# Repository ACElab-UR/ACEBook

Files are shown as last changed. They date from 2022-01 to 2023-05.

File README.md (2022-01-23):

# Animal Comparative Economics Book

This repository contains the source code for the **ACEBook** - ACElab's online JupyterBook.

All code in this project was written in and tested with R 3.xx and Python 3.xx, though older language versions (including R 2.xx and Python 2.7) should work in most cases.

## Usage

### Building the book

If you'd like to develop and/or build the ACEBook, you should:

- Clone this repository
- `cd` to it and run `pip install -r requirements.txt` (it is recommended you do this within a virtual environment - i.e. conda)
- (Recommended) Remove the existing `ACEBook/content/_build/` directory
- Run `jupyter-book build ...` (more on this below)

A fully-rendered HTML version of the book will be built in `ACEBook/_build/html/`.

### Hosting/Deploying the book online

The html version of the book is hosted on the `gh-pages` branch of this repo, which is then rendered on [https://acelab-ur.github.io/ACEBook/](https://acelab-ur.github.io/ACEBook/). 

The following workflow is used to build the book manually:

- Make changes to the book's content on the master branch of this repository
- Re-build the book with `jupyter-book build content` (assumes you are running the command from *root* directory of the repository)
- Ensure that an HTML has been built for each page of your book. There should be a collection of HTML files in the `content/_build/html` folder. Also load `_build/html/notebooks/index.html` and check that the book has been built (with navigation etc.) as expected. 
- Run `ghp-import -n -p -f content/_build/html` to deploy the book.
 
The last command will automatically push the latest build to the `gh-pages` branch. More information on this hosting process can be found [here](https://jupyterbook.org/publish/gh-pages.html#manually-host-your-book-with-github-pages).

Typically after a few minutes the site should be viewable online at [https://acelab-ur.github.io/ACEBook/](https://acelab-ur.github.io/ACEBook/). If not, check repository settings under Options -> GitHub Pages to ensure that the gh-pages branch is configured as the build source for GitHub Pages.

An example command to push all new changes to the git repository is:

`git add -A && git commit -m "Commit message" && git push -u origin master`

**Please do not push changes for every little edit you make to the book (e.g., after fixing some typos)**. Push only significant changes. Remember, you can deploy the book (by pushing to the `gh-pages` branch using `ghp-import` as explained above) without pushing changes to the `master` branch.

## Other tips:

* Read the [Jupyter Book](https://jupyterbook.org/intro.html) - This is short and to the point and addresses all of the key tools and guidelines succinctly 

* If you want to remove a particular cell from the rendered book [see this](https://jupyterbook.org/interactive/hiding.html#removing-code-cell-content)
  
* If you want to remove a cell when exporting a Jupyter Notebook (outside of Jupyter Book), say as an html, add 
 ```json
    {
    "tags": [
        "remove_cell"
        ]
    }
```
to the metadata of the cells that you want to remove from the output, and then run: 
  ```bash
  jupyter nbconvert younotebookname.ipynb --TagRemovePreprocessor.enabled=True --TagRemovePreprocessor.remove_cell_tags="['remove_cell']" --to html
  ```
  (`html` can be replaced with another export format, such as `pdf`). Read the [`nbconvert` documentation](https://nbconvert.readthedocs.io/en/latest/index.html) for more on exporting/converting.

## Contributors

Henrique Galante | henrique.galante@ur.de

## Credits

This project is created using the excellent open source [Jupyter Book project](https://jupyterbook.org/) and the [executablebooks/cookiecutter-jupyter-book template](https://github.com/executablebooks/cookiecutter-jupyter-book).

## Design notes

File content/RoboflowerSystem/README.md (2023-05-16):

# Roboflower System

Welcome to the repository of the Roboflower system!

The Roboflowers are automated artificial flowers from the [ACElab](https://www.animal-economics.com/tjczaczkes) used in behavioural experiments on bumblebees. This READme file details everything about the system, from building the roboflowers to programming experiments, as well as debugging the system. 

Please refer to this document before using the Roboflowers.

## Files in the repository:

### Instructions
Find the readme files to assemble, program and debug the Roboflowers:

- Programming.md
- Assemblingflowers.md
- Harware.md

### Versions
Find the annotated python modules for each Roboflowers' version

### Circuit
Find the schematics and gerber files for the Roboflowers' PCB

### Misc
Find the aruco codes and various files for updating the Roboflower system

## Log changes:
Track the changes brought to the Roboflowers in each version:

### V2023.03.12:
- all python modules are now annotated for clarity
- pumps now have individual calibration rather than one calibration for all 4 pumps per flower
- new operating system for the roboflowers:
	- latest upgrades and updates for packages
- main.py of the HUB re-written in a simpler way
- connect.py (HUB) modifications:
	- the connection with the flowers is now checked every minute 
- main.py (Flower) modifications:
	- pumps' UlForTurn are now invididually precised for each roboflower
	- routine for testing that the RGB LEDs are working properly
- connect.py of the Flower modifications:
	- addition of a "on_disconnect" function that tries to reconnect the flower if it loses the connection with the broker
- electronics.py of the Flower modifications:
	- addition of the parameter "UlForTurn" in the Pump class
	- addition of the parameter "duration" in the blink method
	- precision of the exact volumes delivered in the priming routine in the "prime" function

### V2023.04.13:
In this version: the roboflowers are stable and work well!
- corrected the "too many values to unpack" bugs in routines.py
- fixed the on_disconnect function in both connect.py
- all modules further annotated for clarity
- improved the way log and debug files are written
- corrected the camera error in colonylearn

### V2023.05.04:
- in Electronics:
 	- increased the amount flushed out by the empty pump from 20 to 25ul (to avoid any leaking risk due to calibration imprecision)
 	- in the clean() function, empty pump now flushes out 25ul instead of 21ul 
 	- changed back the "error" from -100/100 to -95/95 for the pumps
- hardware:
 	- changed the big milkers for glass bottles which are no longer suspended above the flowers (reduce capillary action in the tubes + risk of flooding the flowers)
 	- removed the glass pieces in the flowers because of condensation and droplets

### V2023.05.16:
- fixed marker detection

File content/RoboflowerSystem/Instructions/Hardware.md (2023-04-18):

# Hardware
In this section are detailed the specifics of the different electronic components of the Roboflowers.

## Motors
The Roboflowers use [mini brushed DC stepper motors](https://ecksteinimg.de/Datasheet/MO01052/Datenblatt.pdf) (see specifications of the motor)

**What is a stepper motor?**

Stepper motors are DC motors that move in discrete steps. They have multiple coils that are organized in groups called "phases". By energizing each phase in sequence, the motor will rotate, one step at a time. Typical stepper motors are 1.8 degrees per step, which is 200 steps per revolution.

**How to control the motors?**

On the PCB, the two [H-bridges](https://www.ti.com/lit/ds/symlink/l293d.pdf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) (= integrated circuits that enable a voltage to be applied in either direction) are responsible for controlling the motors of the pumps. 
These H-bridge include four independent half-H drivers that can control the direction and speed of DC motors. In our setup, the H-brigdes also serve as our stepper motors' driver boards. 

By sending signals through its GPIO pins, the Raspberry Pi can control the flow of current through the H-bridge circuits, hence controlling the movement of each peristaltic pump.
The Roboflowers have 2 full H-bridges:
- one is used to control the forward movement of the motors, providing a positive voltage
- the other is used to control the backward movement of the motors, providing a negative voltage

To move the motor in one direction, one pair of coils needs to receive a current while the other pair needs to be turned off.

## Pumps
In order to deliver precise amounts of liquid, our motors are programmed precisely to prevent issues such as missed steps or motor vibration. Some basics:
- delay: is the time interval between each step that the motor takes. This is an important parameter that determines the speed of the motor. The smaller the delay, the faster the motor will spin.
- static: is used to determine if the motor is stuck or not. In the code, static is a counter that keeps track of how many times the error is within a certain threshold (in this case, between -5 and 5): if the error is within the threshold for a certain number of times, it means the motor is not stuck and can continue to move.
- updatedspeed: this variable is the new speed that the motor will move at, based on the error calculated from the desired volume and the current position of the motor. It is calculated as error * 0.045 
- 0.045: is the constant that determines the relationship between the error and the updated speed. Increasing this value makes the motor turn faster because the updatedspeed variable is directly proportional to the error: increasing the constant can help to prevent the motor from getting stuck by ensuring that it is running at a fast enough speed to overcome any resistance or friction.
- 100 and -100: These are the minimum and maximum values for the updated speed

In the class Pump of the module electronics, each pump has its "UlForTurn" own method [*modification brought in the V2023.03.12*]
The "stepsForTurn" method corresponds to the number of steps required for the pump to make a full turn. This value is fixed and determined
by the design of the motor. In our design, 700steps make one full pump turn.

## PCB and components
The Printed Circuit Board is the "blue board" designed especially for the Roboflowers. It is used to connect and control the electronic components of the Roboflower, such as the LEDs and the motors.

Elements on the [PCB](file:///C:/Users/saaa/Documents/bumblebee_documents/RoboFlowerSystem/Circuit/Schematic_PeakEndFlowerShield%20H-bridge_2022-02-22.pdf) (Refer to the schematics for more info):
- U1 in the schematics represents the Raspberry pi <=> the 40 GPIO pins precisely
- JP1 - JP4: connectors for the pumps
- U2 and U3: H-bridges for controlling the motors of the pumps
- J2 + R13-14-15: connector for the two RGB LEDs: the one under the platform and the one in front of the roboflower
- U8: MT3608 Step Up <=> voltage booster or voltage regulator module that can increase the voltage level of the input voltage to a higher level

**J2 8p 2mm connector:**

"J" stands for "jack", convention used in electronics to name connectors. This connector is for the 2 RGB LEDs of the Roboflowers, which have 7 pins (2black wires connected to the same pin) spaced 2mm apart.

The J2 connector is connected to the two RGB LEDs using eight wires for 7 pins: two black wires for the anode and cathode (= connected to ground for all LEDs), two blue wires, two green wires, and two red wires. RGB LEDs are light emitting diodes that can produce a range of colors by varying the intensity of red, green, and blue light. The two RGB LEDs are wired in parallel and connected to the J2 connector.
The two RGB LEDs  receive the same voltage and current and emit the same colors at the same time, being wired in parallel. The Raspberry Pi sends the same PWM (Pulse Width Modulation) signals to each of the red, green, and blue elements of the LED to control the brightness and color of the LED.
Typically, the red wire is the positive (+) voltage supply, the black wire is the negative (-) voltage supply or ground, and the other wires are for the individual color channels of the RGB LED.

For example, one green wire might be connected to the green channel of the first RGB LED, and the other green wire might be connected to the green channel of the second RGB LED. The same applies to the other color channels, so there should be one red wire and one black wire for each RGB LED, and two wires for each of the three color channels (red, green, and blue).

**U1 (= Raspberry Pi):**

"U" is often used to represent an integrated circuit or, chip. These are small electronic components that contain many electronic circuits on a single chip of semiconductor material. They are often used in complex electronic systems to perform various functions. U1 means the first chip or integrated circuit in the circuit. U1 is the Raspberry Pi, responsible for controlling and communicating with all the other components on the PCB through its 40 GPIO pins.

**JP1 - JP4: connectors for the pumps:**

"JP" (for jumper) is a small piece of hardware that is used to connect two points or terminals on a circuit board. It is usually a small plastic block with pins. JP1 to JP4 are connectors for the motors of the roboflowers. They allow the motors to be easily connected and disconnected from the rest of the circuit.

Each JP connector has 6pins connected to 6 wires of the following colours: white, blue, green, yellow, black and red.
- white: is the "step" pin, which controls the movement of the stepper motor. The stepper motor moves in precise steps, and each step is triggered by a pulse on this pin
- blue: is the "direction" pin, which controls the direction of the stepper motor. Depending on the signal on this pin, the motor will move in either a clockwise or counterclockwise direction
- green: is the "enable" pin, which allows the motor to be turned on and off. When this pin is high, the motor is enabled and can move. When it's low, the motor is disabled and won't move
- yellow: is the "MS1" pin, which controls the microstepping mode of the motor driver. Microstepping allows for smoother and more precise movements of the motor, but it also requires more processing power and can be slower than full-step mode
- black: is the "ground" pin, which provides a reference voltage for the other pins.
- red: is the "power" pin, which provides the voltage for the motor

**U2 and U3: H-Bridges for the motors:**

the H-bridges are connected to the JP1 to JP4 connectors and to the GPIO pins on the Raspberry Pi. Some of the GPIO pins of the Raspberry pi are specifically connected to the H-bridges to control the direction and speed of the motors.

**U8, MT3608 Step Up:**

The MT3608 Step Up is a DC-DC converter that is commonly used to step up the voltage from a lower voltage source to a higher voltage level. The Raspberry Pi's GPIO pins provide a 5V voltage level, but our motors require a 6V voltage level. The MT3608 Step Up module has an inductor and a switching transistor. There is a back and forth exchange of current between the two change the magnetic which causes to change the voltage. Once the voltage has been boosted to 6V, it is sent to the motors through the H-bridge drivers, allowing the motors to operate at their optimal voltage level.

# Fixing hardware
In this section are detailed the most common problems you may face with the hardware.

## Pump problems

### One pump turns non-stop:
- Wiring issue: the signal to turn off the pump is not being received: double-check the wiring connections (green LED of the motor should be on)
- Calibration issue: the flow rate for the faulty pump is not properly set. Check the calibration values for this pump
- Motor issue: the pump is not responding to the signal to turn off. Try replacing the motor with a new one and see if the issue persists
- Mechanical issue: check the pump for any blockages or obstructions that may be preventing it from functioning properly

### One pump is turning in the wrong direction:
- Direction issue: check that the pump is turning anticlockwise when delivering solution from the bottle to the feeder
- Pump was mounted wrong: check that the pump was assembled correctly (see: AssemblingFlowers.md)
- Connector issue: check that the wires on the JP connectors are mounted correctly: white, blue, green, yellow, black and red

### The motor is vibrating but does not turn:
When a motor vibrates, it means it’s not receiving enough power to move past its initial position, so the motor is just moving very slowly. Check that the current received by the motor is enough (6V):
- set the multimeter to measure DC voltage: place cursor on 20V
- connect the probes to the power supply terminals of the motor:
	- the positive probe (red) touching the red wire on the JP connector
	- the negative probe (black) touching the black wire on the connector
	- make sure the motor is running while you take the measurement: this will give you an accurate reading of the voltage being supplied to the motor while it is under load
- lubricate the motor that gets stuck
- change constant in the code (0.045) and/or add time.sleep between each step motor step

## LEDs problems

### One of the LED doesn't light up during the routine when starting a Roboflower:
- Faulty LED: try swapping the LED with a known-working LED to see if the problem is with the LED itself
- Wiring issue: check the connections on the PCB and the J2 connector to ensure that the wires are connected properly and not loose
- Power issue: the power supply to the LED is not sufficient and is not getting enough voltage to light up. check the voltage levels using a multimeter to ensure that the power supply is providing the correct voltage:
    - Red LEDs typically require a voltage of around 1.8 to 2.2 volts to light up
    - Blue LEDs: around 3.0 to 3.6 volts to light up
    - Green LEDs: around 2.0 to 3.6 volts to light up

How to check the voltage levels of the LEDs with a multimeter:
- set the multimeter to measure DC voltage (usually denoted as V with a straight line and a dashed line above it)
- connect the black probe of the multimeter to the ground (GND) pin <=> touch the black pin of the connector on the PCB
- connect the red probe of the multimeter to the positive (+) pin of the power supply <=> touch the coloured pin of the connector on the PCB

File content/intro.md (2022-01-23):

Welcome to The Animal Comparative Economics Book!
===================================================

```{epigraph}
Animals must constantly make economic decisions to survive. Understanding the preference for one option over another is key to decision making. We are building on insights from the study of behavioural economics and cognitive psychology in order to understand how animals evaluate options, and thus make decisions, both alone and collectively.
Our research focuses mostly on invertebrates, especially ants, as they offer a fast and flexible platform for testing decision making.
```

## Team
<hr style="border:2px solid gray"> </hr>

### PD Dr. Tomer J. Czaczkes
**Team Leader**  
Leads all ACE research projects, and is also involved in a wide variety of behavioural ecology projects. Collects data on occasion.
 
### Dr. Massimo de Agro
**Post-Doctoral Researcher**  
In charge of developing a robotic flower meadow for our bumblebees. Cameras! Micro-computers! Lots and lots of mini-pumps! Also does spider vision research in his spare time.

### Mélissa Armand
**Doctoral Researcher**  
Studies how plants may be using behavioural economics to manipulate pollinators - in our case bumblebees.

### Henrique Galante
**Doctoral Researcher**  
Studies how preference can be steered in Argentine ants using behavioural economics and comparative psychology. Works closely with Thomas Wagner.

### Thomas Wagner
**Doctoral Researcher**  
Studies how preference can be steered in Argentine ants using behavioural economics and comparative psychology. Works closely with Henrique Galante.

### Alexandra Koch
**Research Assistant**  
A long-term fixture in the ACElab, Alex does... everything.

### MSc & BSc students
Sophie Schmid - **BSc thesis**  
The effect of urban heat islands on ant behaviour

Melina Kienitz - **BSc thesis**  
Visual discrimination of sucrose in Bumblebees

### PhD Alumni
Dr. Felix Oberhauser  
Dr. Stephanie Wendt  
Dr. Massimo de Agro

### MSc and BSc Alumni
Chiara Matschunas  
Melanie Kabas  
Alexandra Koch  
St. Popp  
Caroline Hübner  
Jack Beckwith  
Daniel Grimwade  
Pragya Kumar  
Stealth Human  
Countless 3-week and 6-week practical students: you know who you are!

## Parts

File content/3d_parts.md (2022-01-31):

# 3D Printing
## Feeders

<font size = "+0"> <b> <a href = "https://github.com/ACElab-UR/ACEBook/raw/main/content/3D_Parts/water_feeder.stl" download = "water_feeder.stl" style = "color: DarkOrange" > Water Feeder </a> </b> </font>

<font size = "+0"> <b> <a href = "https://github.com/ACElab-UR/ACEBook/raw/main/content/3D_Parts/sucrose_feeder.stl" download = "sucrose_feeder.stl" style = "color: DarkOrange" > Sucrose Feeder </a> </b> </font>

<font size = "+0"> <b> <a href = "https://github.com/ACElab-UR/ACEBook/raw/main/content/3D_Parts/tiny_feeder.stl" download = "tiny_feeder.stl" style = "color: DarkOrange" > Tiny Feeder </a> </b> </font>

## Nests

<font size = "+0"> <b> <a href = "https://github.com/ACElab-UR/ACEBook/raw/main/content/3D_Parts/nest_tube_holder.stl" download = "nest_tube_holder.stl" style = "color: DarkOrange" > 15mL Falcon Holder </a> </b> </font>

## Y-Maze Parts

<font size = "+0"> <b> <a href = "https://github.com/ACElab-UR/ACEBook/raw/main/content/3D_Parts/y_maze_wall.stl" download = "y_maze_wall.stl" style = "color: DarkOrange" > Y-Maze Wall </a> </b> </font>

<font size = "+0"> <b> <a href = "https://github.com/ACElab-UR/ACEBook/raw/main/content/3D_Parts/linear_wall.stl" download = "linear_wall.stl" style = "color: DarkOrange" > Linear Wall </a> </b> </font>

<font size = "+0"> <b> <a href = "https://github.com/ACElab-UR/ACEBook/raw/main/content/3D_Parts/double_y_maze_1.stl" download = "double_y_maze_1.stl" style = "color: DarkOrange" > Double Bifurcation Y-Maze 1 </a> </b> </font>

<font size = "+0"> <b> <a href = "https://github.com/ACElab-UR/ACEBook/raw/main/content/3D_Parts/double_y_maze_2.stl" download = "double_y_maze_2.stl" style = "color: DarkOrange" > Double Bifurcation Y-Maze 2 </a> </b> </font>

## Moats & Bridges

<font size = "+0"> <b> <a href = "https://github.com/ACElab-UR/ACEBook/raw/main/content/3D_Parts/moat_vM.stl" download = "moat_vM.stl" style = "color: DarkOrange" > Moat - Massimo Version </a> </b> </font>

<font size = "+0"> <b> <a href = "https://github.com/ACElab-UR/ACEBook/raw/main/content/3D_Parts/8cm_bridge_vM.stl" download = "8cm_bridge_vM.stl" style = "color: DarkOrange" > 8cm Bridge - Massimo Version </a> </b> </font>

<font size = "+0"> <b> <a href = "https://github.com/ACElab-UR/ACEBook/raw/main/content/3D_Parts/moat_vH.stl" download = "moat_vH.stl" style = "color: DarkOrange" > Moat - Henrique Version </a> </b> </font>

<font size = "+0"> <b> <a href = "https://github.com/ACElab-UR/ACEBook/raw/main/content/3D_Parts/6cm_bridge_vH.stl" download = "6cm_bridge_vH.stl" style = "color: DarkOrange" > 6cm Bridge - Henrique Version </a> </b> </font>

<font size = "+0"> <b> <a href = "https://github.com/ACElab-UR/ACEBook/raw/main/content/3D_Parts/7cm_bridge_vH.stl" download = "7cm_bridge_vH.stl" style = "color: DarkOrange" > 7cm Bridge - Henrique Version </a> </b> </font>

<font size = "+0"> <b> <a href = "https://github.com/ACElab-UR/ACEBook/raw/main/content/3D_Parts/8cm_bridge_lego.stl" download = "8cm_bridge_lego.stl" style = "color: DarkOrange" > 8cm Bridge - Lego Version </a> </b> </font>

## Aluminium Extrusion Supports

<font size = "+0"> <b> <a href = "https://github.com/ACElab-UR/ACEBook/raw/main/content/3D_Parts/alu_profile_camera_support_4.0.stl" download = "alu_profile_camera_support.stl" style = "color: DarkOrange" > Camera Support </a> </b> </font>

<font size = "+0"> <b> <a href = "https://github.com/ACElab-UR/ACEBook/raw/main/content/3D_Parts/alu_profile_screen_support_half_1.stl" download = "alu_profile_screen_support_half_1.stl" style = "color: DarkOrange" > Screen Support 1 </a> </b> </font>

<font size = "+0"> <b> <a href = "https://github.com/ACElab-UR/ACEBook/raw/main/content/3D_Parts/alu_profile_screen_support_half_2.stl" download = "alu_profile_screen_support_half_2.stl" style = "color: DarkOrange" > Screen Support 2 </a> </b> </font>

## Volume Estimation Parts

<font size = "+0"> <b> <a href = "https://github.com/ACElab-UR/ACEBook/raw/main/content/3D_Parts/volume_estimation_base.stl" download = "volume_estimation_base.stl" style = "color: DarkOrange" > Base </a> </b> </font>

<font size = "+0"> <b> <a href = "https://github.com/ACElab-UR/ACEBook/raw/main/content/3D_Parts/volume_estimation_platform.stl" download = "volume_estimation_platform.stl" style = "color: DarkOrange" > Platform </a> </b> </font>

## Survival Assay Parts

<font size = "+0"> <b> <a href = "https://github.com/ACElab-UR/ACEBook/raw/main/content/3D_Parts/cell_culture_lid_23cm.stl" download = "cell_culture_lid_23cm.stl" style = "color: DarkOrange" > 23cm Lid </a> </b> </font>

<font size = "+0"> <b> <a href = "https://github.com/ACElab-UR/ACEBook/raw/main/content/3D_Parts/cell_culture_lid_24cm.stl" download = "cell_culture_lid_24cm.stl" style = "color: DarkOrange" > 24cm Lid </a> </b> </font>

## Assorted Parts

<font size = "+0"> <b> <a href = "https://github.com/ACElab-UR/ACEBook/raw/main/content/3D_Parts/plate_cleaner.sl1" download = "plate_cleaner.sl1" style = "color: DarkOrange" > SL1 Plate Cleaner </a> </b> </font>

<font size = "+0"> <b> <a href = "https://github.com/ACElab-UR/ACEBook/raw/main/content/3D_Parts/vaccum_plug.stl" download = "vaccum_plug.stl" style = "color: DarkOrange" > Vaccum Plug </a> </b> </font>

<font size = "+0"> <b> <a href = "https://github.com/ACElab-UR/ACEBook/raw/main/content/3D_Parts/epi_holder.stl" download = "epi_holder.stl" style = "color: DarkOrange" > Eppendorf Holder </a> </b> </font>

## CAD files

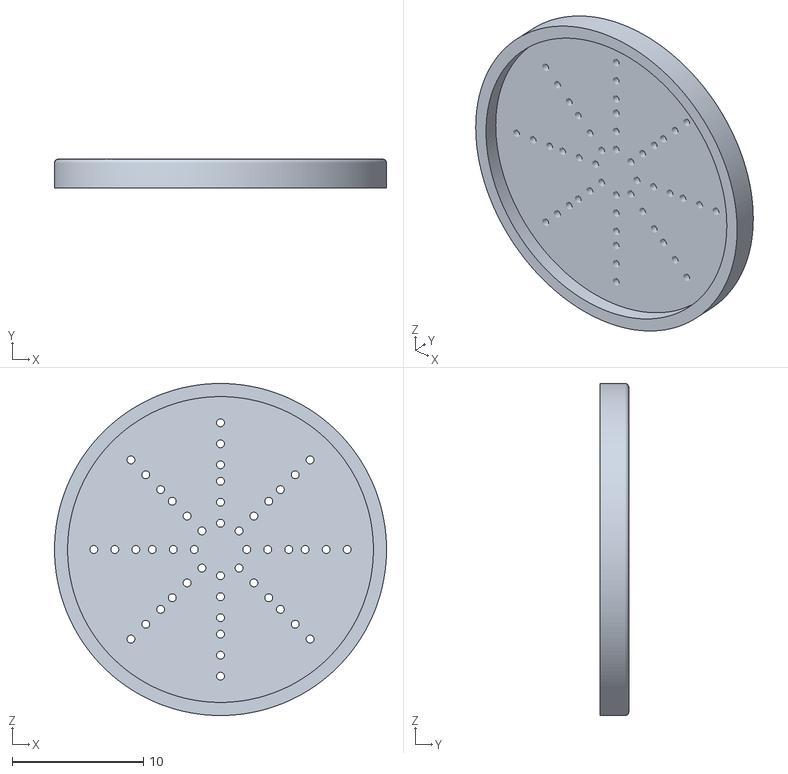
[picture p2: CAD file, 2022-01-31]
content/3D_Parts/cell_culture_lid_23cm.stl
25.3 x 2.20 x 25.3

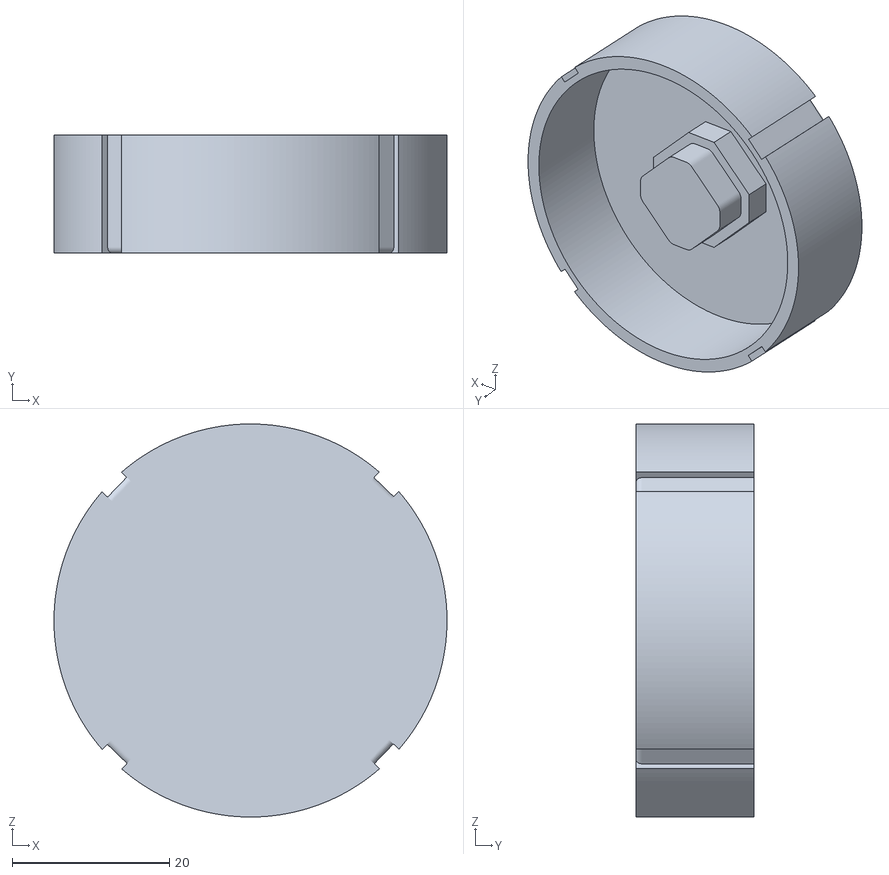
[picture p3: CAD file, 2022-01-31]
content/3D_Parts/moat_vH.stl
50.0 x 15.0 x 50.0

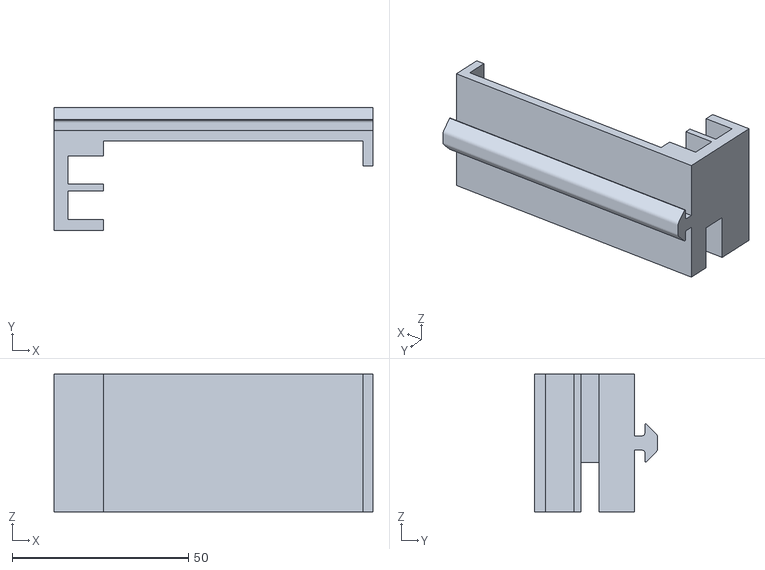
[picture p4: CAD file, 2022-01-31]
content/3D_Parts/alu_profile_screen_support_half_1.stl
90.5 x 35.0 x 39.1

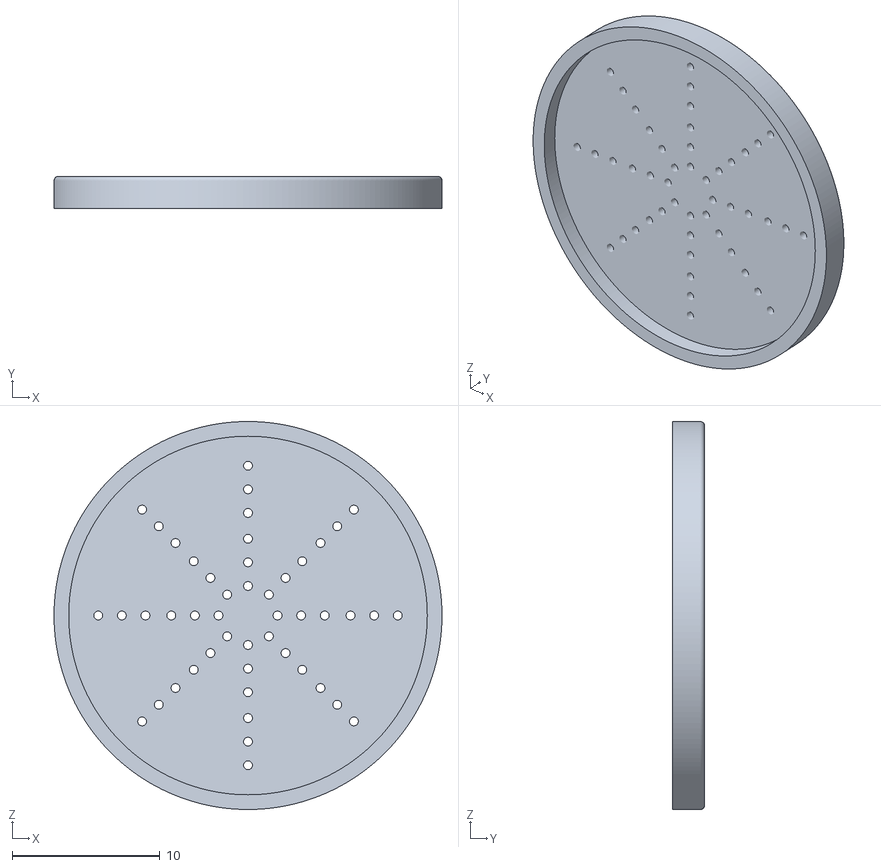
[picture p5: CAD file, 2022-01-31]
content/3D_Parts/cell_culture_lid_24cm.stl
26.3 x 2.20 x 26.3

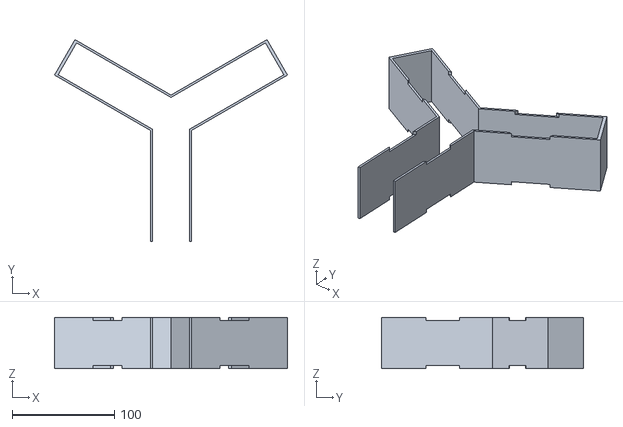
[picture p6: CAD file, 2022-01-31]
content/3D_Parts/y_maze_wall.stl
227.8 x 197.3 x 50.0

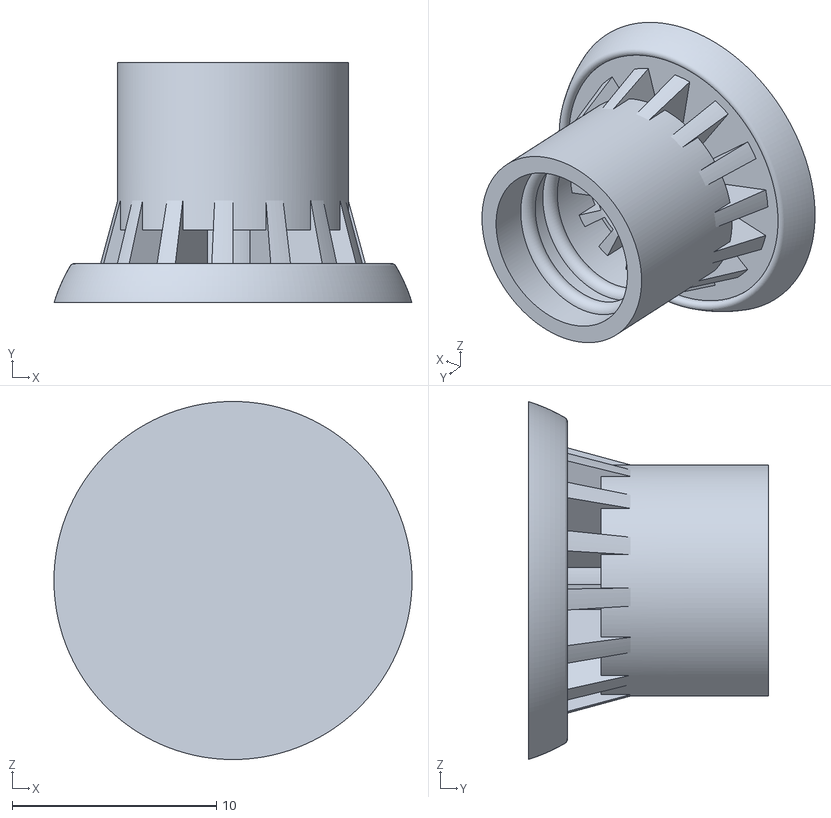
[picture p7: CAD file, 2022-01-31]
content/3D_Parts/tiny_feeder.stl
17.5 x 11.8 x 17.5

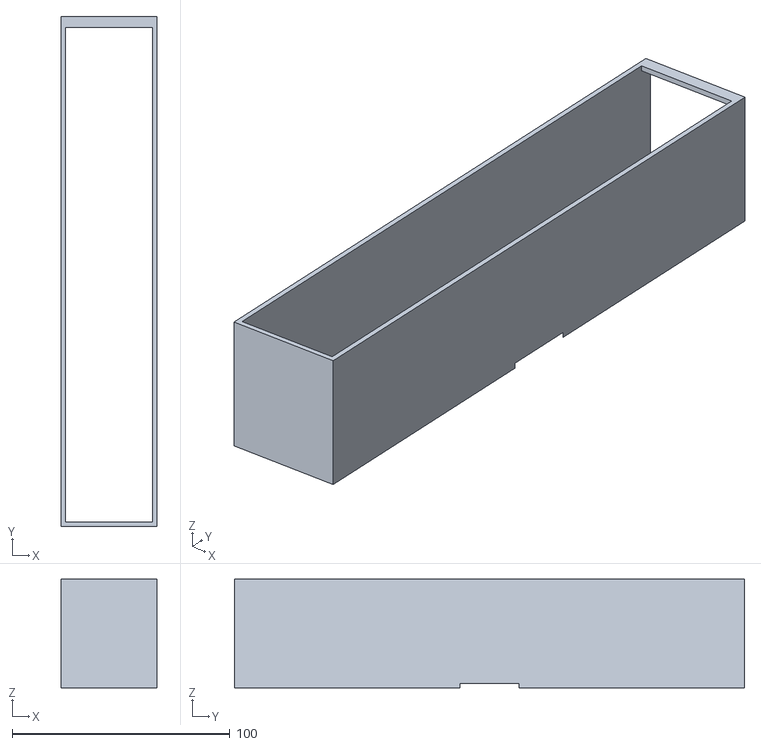
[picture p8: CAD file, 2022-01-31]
content/3D_Parts/linear_wall.stl
44.0 x 234.0 x 50.0

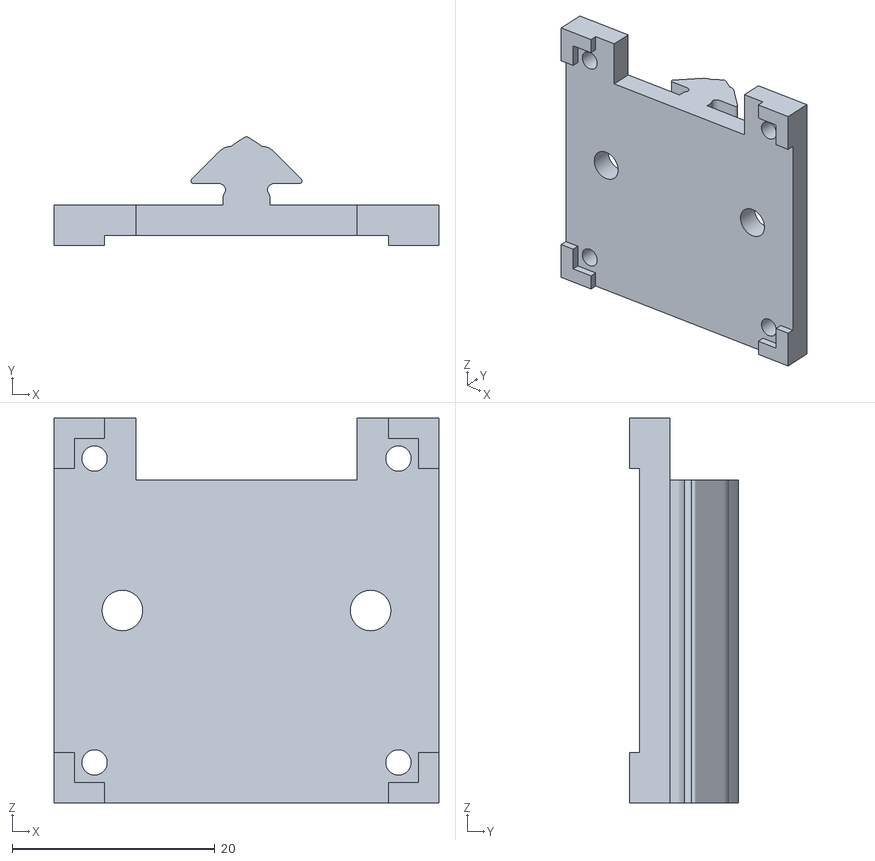
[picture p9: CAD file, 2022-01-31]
content/3D_Parts/alu_profile_camera_support_4.0.stl
38.0 x 10.8 x 38.0

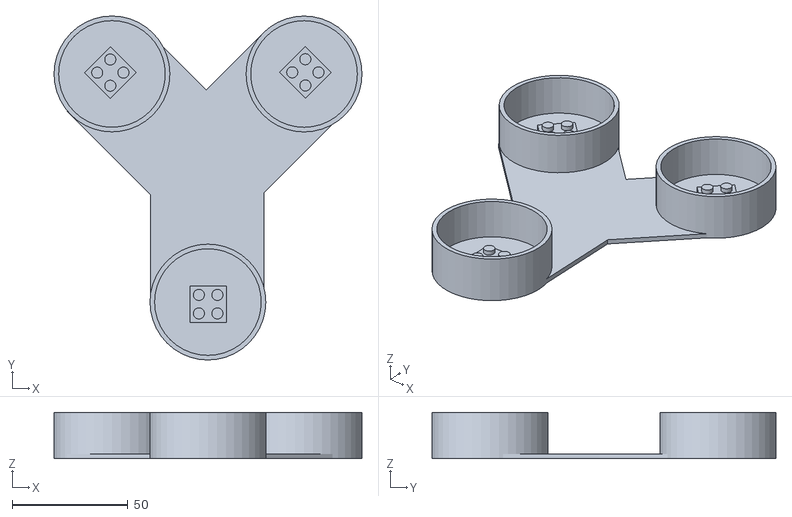
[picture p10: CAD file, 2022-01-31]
content/3D_Parts/double_y_maze_1.stl
132.9 x 148.4 x 20.0

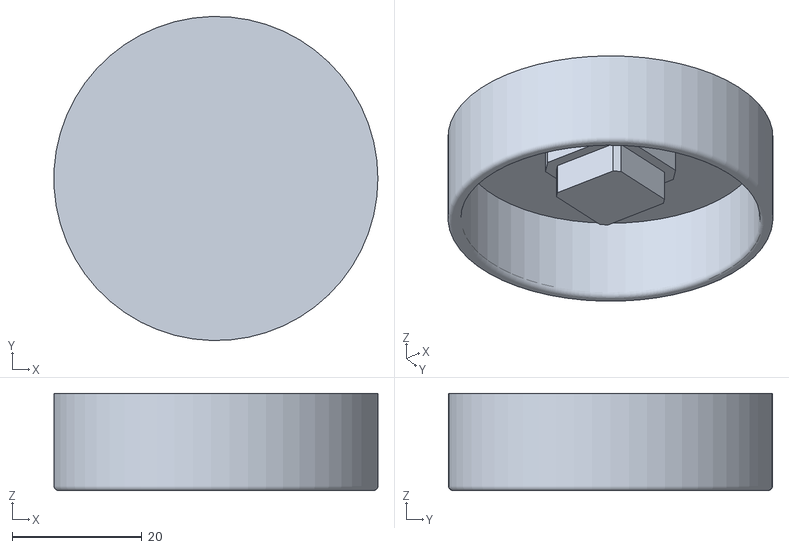
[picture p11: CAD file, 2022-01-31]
content/3D_Parts/moat_vM.stl
50.0 x 50.0 x 15.0

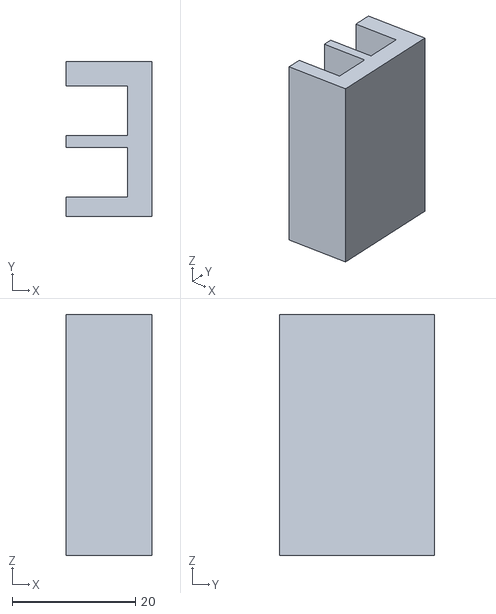
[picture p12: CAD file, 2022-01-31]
content/3D_Parts/alu_profile_screen_support_half_2.stl
14.0 x 25.2 x 39.1

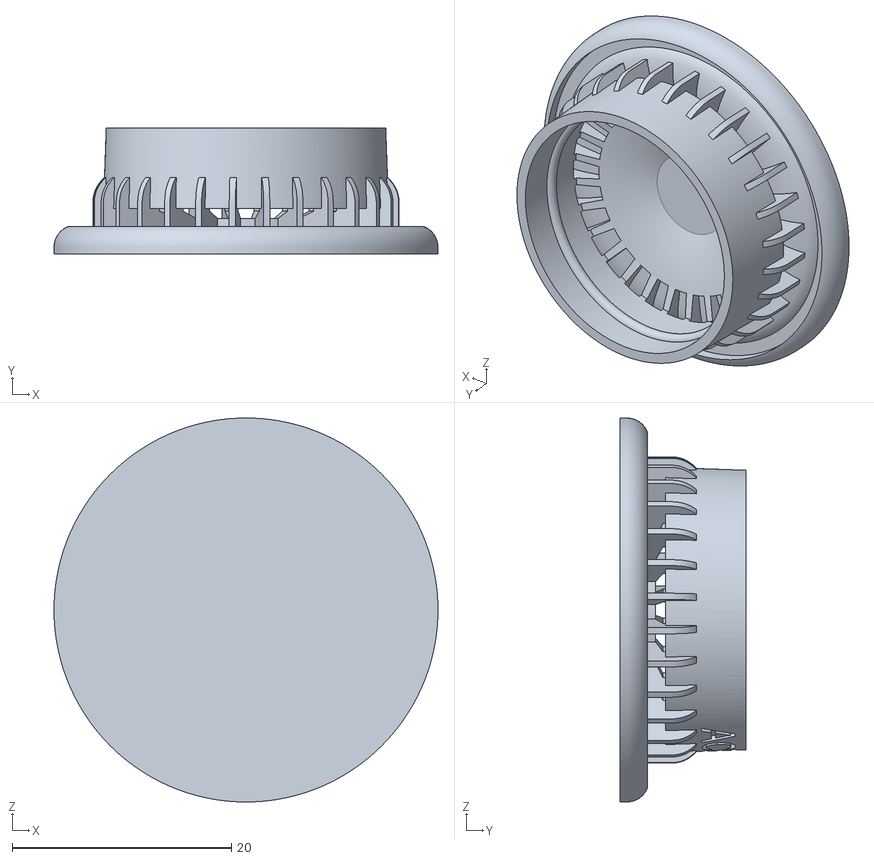
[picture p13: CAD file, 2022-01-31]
content/3D_Parts/water_feeder.stl
35.0 x 11.5 x 35.0

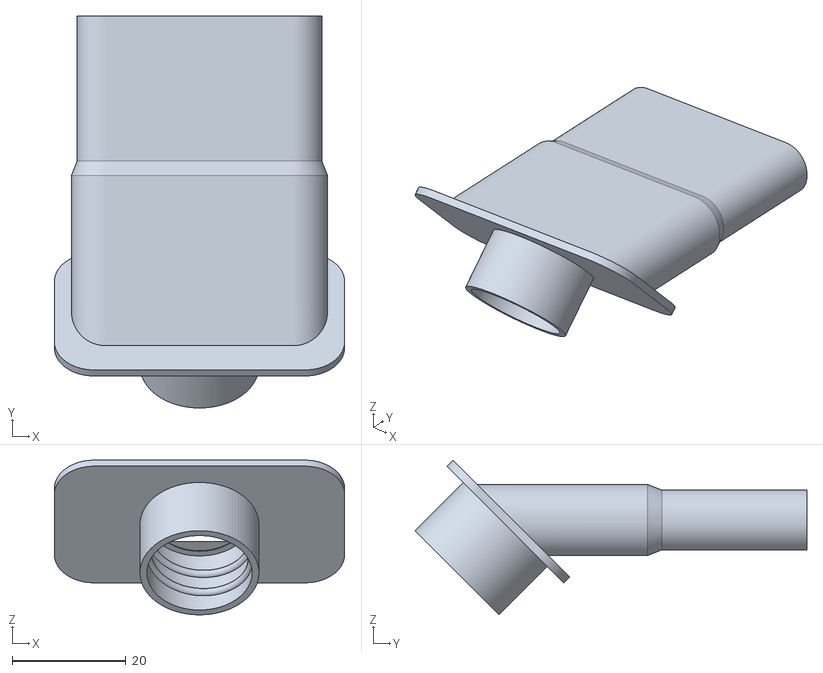
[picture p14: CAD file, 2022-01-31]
content/3D_Parts/vaccum_plug.stl
51.0 x 68.9 x 27.2

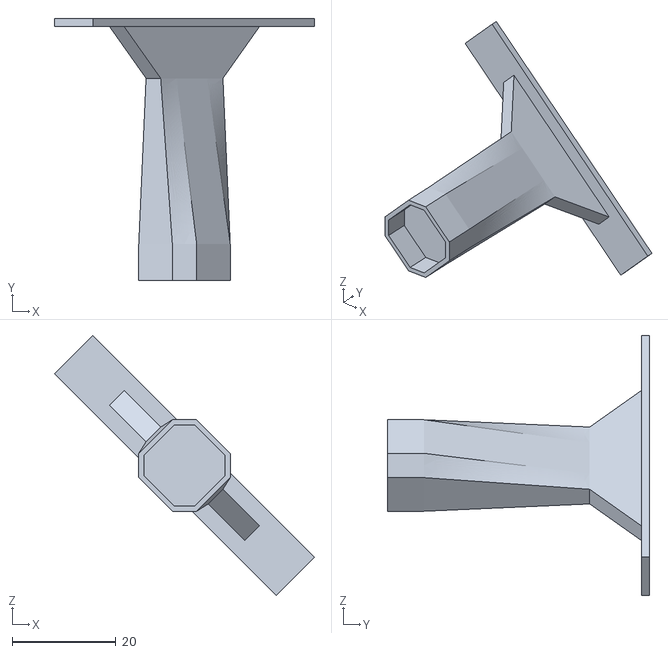
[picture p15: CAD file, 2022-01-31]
content/3D_Parts/6cm_bridge_vH.stl
50.2 x 50.5 x 50.2

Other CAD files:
content/3D_Parts/sucrose_feeder.stl
content/3D_Parts/nest_tube_holder.stl
content/3D_Parts/8cm_bridge_vM.stl
content/3D_Parts/volume_estimation_base.stl
content/3D_Parts/7cm_bridge_vH.stl
content/3D_Parts/8cm_bridge_lego.stl
content/3D_Parts/double_y_maze_2.stl
content/3D_Parts/epi_holder.stl
content/3D_Parts/volume_estimation_platform.stl

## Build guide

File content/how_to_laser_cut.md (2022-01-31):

# Laser Cutting Guidelines

**Laser**: VLS2.30 | **Contact Person**: Florian Weinzierl (Florian2.Weinzierl@chemie.uni-regensburg.de)

## UPON ARRIVAL
Do not forget to book a laser cutting slot online using the GroupWise calendar. Tell someone that you are going to be using the laser cutter.
- Sign the user book and specify what materials will be cut (red book right of the computer)
- Turn computer ON (bottom right of the screen - underneath)
- Switch ON the USB hub (the laser won't work if it is OFF)
- Once computer is ON switch the laser ON by pressing its “POWER” button
## USING CORELDRAW
Do not connect the laser computer to the internet and do not update the CorelDraw version on it. You can either open a CorelDraw file or import an SVG file.
If importing an SVG file:
- Unlock the shape – Press the shape > Ungroup > Press the shape > Unlock > Press the shape > Ungroup
- Make all cutting lines red and make their thickness “hairline” – Right-most vertical tab > Object properties > Press the shape > Line thickness (top dropdown menu) = “hairline”
- Make all engraving lines black.
- If multiple laser passes are required, for example to cut 3 pieces of paper in one go, simply copy and paste the shapes on top of each other that many times. The laser will recognize multiple cut layers but not multiple engraving layers.
## CUTTING
Do not stare directly at the laser and avoid leaving it unattended for long periods of time. If unsure of anything, please reach out for help before doing it.
If repeating a print:
- Open VLS2.30 > Use the history tab on the upper-left corner to reopen a previous file.
- Open the laser lid and align the laser and the material by using “Focus View” (button next to the magnifying glass) and pressing different areas of the cutting area checking where they fall in the material.
- Close the laser lid and turn the fan ON (LVL 3 for paper and LVL 5 for wood and acrylic – to do this press both arrows until the green light starts blinking and then adjust the level).
- Press the PLAY button to initiate cutting.
If launching a new print:
- Once the CorelDraw file is ready select the shapes of interest
- Press print > Ensure that “Current Selection” is selected > Go to the layout tab (this fixes a bug which rescales the print automatically) > Back to overview > Preferences > Load the laser settings needed (can use a preset in the ACElab folder) > Press OK > Press Print > Move to VLS2.30
- Open the laser lid and align the laser and the material by using “Focus View” (button next to the magnifying glass) and pressing different areas of the cutting area checking where they fall in the material.
- Close the laser lid and turn the fan ON (LVL 3 for paper and LVL 5 for wood and acrylic – to do this press both arrows until the green light starts blinking and then adjust the level).
- Press the PLAY button to initiate cutting.
## CHANGING LASER SETTINGS
It is always best to try these on a small portion of the material before cutting the desired shape.

Laser settings include:
>	**Power**  

>	**Speed**  

>	**PPI (pulses per inch)** – higher is slower but better resolution  

>    **Z-axis correction** defines how thick the material is  

>    Different **colors** for engraving and cutting can be used – if the shape selection contains multiple colors do not forget to skip the ones that are not meant to be used
## CHANGING & CLEANING BEDS
There are two beds - normal cutting bed & engraving bed (which has rulers around its edges). The cutting bed is used for wood and acrylic, does not require thorough cleaning and usually stays inside the laser. The engraving bed is used for paper or if a more precise alignment is required, it is usually kept in a cupboard underneath to the right of the computer and requires cleaning after use.
To change the bed:
- Move the bed all the way down using the laser arrow buttons
- Unscrew the bed and remove it being careful not to hit the laser
- The cutting bed (for wood and acrylic) does not get screwed in, however ensure that it sits firmly and the connectors at its base are plugged in
- After removing a bed, the laser height needs to be reset. To do this, go to VLS2.30 to Focus View > Go > Adjust Z height = -0.5mm
To clean the engraving bed: 
- Ensure both sides of the bed are clean
- Start with Scheuermilch (yellow detergent bottle)
- Water
- Acetone
- Place back in cupboard (underneath to the right of the computer)
## BEFORE LEAVING
Leave the place as you found it or better! Clean after yourself and do not leave material behind unless previously agreed upon.
- Switch the laser OFF by pressing its “POWER” button
- Ensure the laser fan is OFF
- Turn computer OFF
- Switch OFF the USB hub
- Ensure the beds, cleaning products and materials are all in their respective places
- Turn OFF the lights

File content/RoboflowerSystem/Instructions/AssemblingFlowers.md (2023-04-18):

# Building the pumps

The Roboflowers are equipped with 4 peristaltic pumps, each bringing sucrose solution or water to the feeder inside the flowers via a tubing system:

- Pump 1 (or called 0 in python modules): delivers sucrose of concentration of choice
- Pump 2 (or called 1 in python modules): delivers sucrose of concentration of choice, or water
- Pump 3 (or called 2 or "waterpump" in python modules): delivers water to wash out sucrose from the feeder
- Pump 4 (or called 3 or "emptypump" in python modules): flushes out the mix of water/sucrose remaining in the feeder

## Mounting the pumps

### Crafting the pumps

Files for 3D printing the different pump parts in resin:

- Case and lid: [pumpV19_case_lid.sl1](..%2Fbumblebee_server%2F3D_Design%2FRoboFlower%2FPump%2FV19_final%2Fto_3d_print%2FpumpV19_case_lid.sl1)
- Impeller: [pumpV19_impellers.sl1](..%2Fbumblebee_server%2F3D_Design%2FRoboFlower%2FPump%2FV19_final%2Fto_3d_print%2FpumpV19_impellers.sl1)
- Pushers: [pushersV2_0.65_x25.sl1](..%2Fbumblebee_server%2F3D_Design%2FRoboFlower%2FPump%2FV19_final%2Fto_3d_print%2FpushersV2_0.65_x25.sl1) and [pushersV2_0.70_x25.sl1](..%2Fbumblebee_server%2F3D_Design%2FRoboFlower%2FPump%2FV19_final%2Fto_3d_print%2FpushersV2_0.70_x25.sl1)

Other elements:

- tubing (diameter 0.5mm): 0.5 * 0.5 * 100m silicone tubes
- [bearings](https://www.amazon.de/-/en/gp/product/B07MLZWJ4D/ref=ox_sc_act_title_2?smid=A2437MEP6E7G5L&psc=1): 2 * 5 * 2.5mm micro steel ball bearings
- [step motors](https://eckstein-shop.de/V-TEC6VMicro10x12mmDCMotorGleichstromGetriebeMotormitEncoder168RPM): see "Motors" section for all details
- various screws (sizes: 1.6; 2)

### Assembling the pumps

Step-by-step process:
- place the bearings x4 in the impeller
- place 1.6 screws in the case and screw motor to the bottom - must be tight
- cut tubing and place in the case
- gently place the impeller inside the case, facing down, until it "clicks"
- pull the tube out and try to fit two bearings around it - make sure the tubing goes around each bearing
- pull the tube to check that the bearings can roll freely
- place screws 2 (x4) on the lid on opposite ends
- screw the pushers (0.65 + 0.70) together with the tubing inside - pushers must be place on the right end of the tubing
- once the pump has been tested, rearrange the tubing so there is a long end on the right side of the pump, and short end on the left side

The peristaltic pumps have a left and right end. When moving forward, the motors turn anticlockwise, making the pump turning anticlockwise as well: liquid flows from the right to the left. For this reason, the pushers are mounted on the right end of the tubing: while the pumps is running, the pushers get pushed against the case of the pump and does not displace the tubing to the left due to rotary force.

### Testing the pumps

The pumps (x4 per flower) need to be tested individually to know exactly how much they push liquid per motor turn. The testing is done using a Roboflower containing the following elements:
- Raspberry pi
- SD card called "TEST" containing the flower files + the pumpTest module
- Picam connected to the camera connector (needed to avoid a python error)
- PCB mounted on the Raspberry pi
- Pump that needs to be tested on the motor #1 connector

Connect the pump to a syringe containing water and let the other end of the tube lose on the table next to a ruler

#### Pump delivering calculation
Plug the raspberry pi (power cord, HDMI cable and keyboard). Once the raspberry pi is done booting, type:
```python
python3 -i pumpTest.py
feeder.deliverPump0.deliver(18000, 255)  # 18000 corresponds to 3 full pump turns (pumps are calibrated on one motor turn = 6uL delivered)
```
This module allows the pump to connect to the PCB's motor connector "0" and deliver 18uL of liquid
Repeat 3times per pump and calculate the mean of water progression (in mm). Make sure that the motor turns effortlessly and that the water flow is consistent. The water progression should be similar in the 3 occurrences - if too variable, discard the pump.

/!\ before calibrating any pump: connect them to a bottle full of water turned upside down and make sure that water doesn't flow through the tubing!
The tubing being really small, there is a risk of water travelling in the tubing through capillarity. If it is the case: discard the pump

### Pump calibration
Method for calibrating a pump:
- run the peristaltic pump for a set number of motor turns, such as 3 turns (=18000)
- /!\ make sure that the motor is running clockwise
- measure the distance between the mark you made on the silicone tubing and the point where the water level has moved to on a graduated ruler
- divide the distance moved by the water by the number of motor turns to get the amount of water delivered per turn of the motor
- repeat this step 3times for more precision
- /!\ if water continues moving through the tube at rest: discard the pump!
- convert this average distance to microliters pushed by one motor turn with the following formula:
	- cross-sectional area of the tubing = πr^2, with r is the radius of the tubing (so 0.25mm in our system because the diameter of the tubing is 0.5mm
	- volume delivered per motor turn (in ul) = cross-sectional area of tubing (in mm^2) x distance moved by water (in mm)
	
For example, if the water moved 10 mm in the calibration test, then the volume delivered per turn would be:
	- volume delivered per turn ≈ 0.196 mm^2 x 10 mm = 1.96 μL per turn (approximately)

Use this [website](https://www.omnicalculator.com/math/cylinder-volume) for easy calculation, with these parameters:
  - radius (in mm) = 0.25
  - diameter (in mm) = 0.5
  - height (in mm) is the distance the water has moved along the graduated ruler
  - volume (in mm^3) is the volume delivered per motor turn for this pump (because 1mm^3 == 1uL)

Pumps range: around 30mmn for one pump full turn <=> approx. 5.5 - 6.5uL per motor turn

## Programming the pumps

Once 4 pumps deliver correctly they can be labelled and registered accordingly in the "calibration_pumps" Excel sheet:
- date of testing
- method for testing the pump (to check for consistency): calibration station or experiment
- associate pumps with 1, 2, 3 and 4: try associating pumps 1 and 2 with the most precise pumps

When done, modify the code accordingly with the delivering power of each pump:

In the main module of the flower:
```python
feeder = electronics.Feeder(electronics.Pump(electronics.pins['motor1fwd'], electronics.pins['motor1bkw'],
		 electronics.pins['motorClk1'], electronics.pins['motorDt1'],
		 electronics.pi, UlForTurn= # value pump1),
		 electronics.Pump(electronics.pins['motor2fwd'], electronics.pins['motor2bkw'],
		 electronics.pins['motorClk2'], electronics.pins['motorDt2'],
		 electronics.pi, UlForTurn= # value pump2),
		 electronics.Pump(electronics.pins['motor3fwd'], electronics.pins['motor3bkw'],
		 electronics.pins['motorClk3'], electronics.pins['motorDt3'],
		 electronics.pi, UlForTurn= # value pump3),
		 electronics.Pump(electronics.pins['motor4fwd'], electronics.pins['motor4bkw'],
		 electronics.pins['motorClk4'], electronics.pins['motorDt4'],
		 electronics.pi, UlForTurn= # value pump4))
```

*note*: see Hardware.md section "fixing pumps problems" if something doesn't work with the pump

# Assembling the Roboflowers

Step-by-step process to build a Roboflower from scratch, or to rebuild a flower after cleaning the different elements in-between experiments

3D design of the complete Roboflower: [RoboFlower.FCStd1](..%2Fbumblebee_server%2F3D_Design%2FRoboFlower%2FRoboFlower.FCStd1)

## Roboflower elements
- Raspberry pi model 4 - 4Go
- SD card flashed with classic ubuntu distribution + Roboflower files
- PCB
- 3D printed parts: flower halves x2: left and right; flower bases x2: top and bottom
- Feeder (max capacity = 50uL)
- PiCamera
- Polycarbonate glass pieces x2 (offers high optical clarity): landing platform and camera piece  
- Grey spray cans for colouring the flower halves and match the arena wall and floor
- white LED x1: to light the inside of the flower so the camera can detect markers 
- RGB LEDs x2 wired in parallel: colours of the flower: one on the front of the flower, the over below the landing platform
- Peristaltic pumps x4
- Connectors for the LEDs and pumps
- Various screws

## Raspberry pi
The Raspberry Pi 4 is the SBC (single-board computer) used for the Roboflowers. We use the RPI 4 which has, among other things:
- 4GB of RAM
- Ethernet connectors
- Bluetooth 5.0
- one micro-SD card slot
- two micro-HDMI ports
- camera connector (CSI-2)

First, check if the Raspberry pi is working, especially:
- if it can read the SD card (see next section)
- if the camera connectors work properly (i.e. no camera error after the rpi is done booting)

To test these, plug the raspberry pi (power cord + HDMI cable) with a flashed SD card and connect a camera to the CSI connector

## SD card and Roboflower files
To use the Raspberry Pi, an OS (operating system) has to be installed on the SD card. The most popular OS for the RPI is the Raspberry Pi OS (formerly known as Raspbian), which is based on Debian Linux.

The installation we use for the roboflowers is based on the Raspberry Pi Lite OS 32-bit (2023.02.21). This "Flower0"
needs to be flashed on an empty SD card for every new flower. /!\ note that Flower0 doesn't have a desktop environment (because it uses a lot of system resources. This means that they cannot display videos because there is no graphical user interface (GUI).

Step-by-step process for flashing a new SD card with Flower0:
- insert the SD card on your computer (Windows works too) - has to be 4Go minimum
- open the Raspberry Pi Imager software and choose the OS you want to install (Flower0)
- select the SD card as the target for the installation
- click "Write" and wait for the process to finish

Once the operating system is installed on the SD card, you can insert the SD card into the Raspberry Pi and power it on

Additional infos about the Roboflowers' OS:
  - login: roboflower
  - psw: ACElab

- "Flower0_original" is the OS created by Massimo in 2021
- Flower0 is the new OS used in the current roboflowers
- additional packages installed: pip3, opencv, paho mqtt, picamera, pigpio, yaml, wiringpi

Once done, some files need to be modified. (/!\ has to be done on an Ubuntu machine to be able to access the partitions on the SD card:
- in the "home/roboflower" folder, place the Flower files and:
  - modify the *config.yaml* with the matching flower number (by convention, use the number noted on the Raspberry pi board)
  - modify the *main.py* with the according delivering values of each pump

- in the "etc" folder, modify the *dhcpcd.conf*:
  - open terminal in the target folder: *sudo nano dhcpcd.conf*
  - de-comment lines of the "eth0" block of code (minus the line \6) and rename the IP address of the flower. Format: 192.168.0.112 (flower 12)

/!\ forcing a fixed IP creates problem accessing internet via wifi or ethernet. Re-comment lines
in dhcpcd.conf if you ever want to reconnect your raspberry pi to internet.

## Camera
For the Roboflowers, we use the PiCamera which is a camera module designed specifically for the Raspberry Pi. It connects to the CSI (Camera Serial Interface) port on the Raspberry Pi board and is controlled using the Python Picamera library.

We use the Picamera to recognize the aruco markers on the bees using the library OpenCV in Python.

### Detecting the bees:

Individual bees are marked with ArUco codes on their thorax. ArUco is a popular library in Python for marker-based augmented reality applications. ArUco markers consist of squares with each
cell of the pattern being either black or white. The pattern is surrounded by a white border to make detection easier. 
The python library associated provides a pre-defined set of marker dictionaries, each containing a set of unique
markers with different sizes and resolutions.

The roboflowers are using the DICT_4X4_250 dictionary, which consists of 250 unique 4x4 bit patterns, each representing 
a unique ID. For the Roboflowers, we are using only the 99 first markers (largely enough for one experiment). 

### Calibrating/testing the camera:

Once the raspberry pi connectors recognize the PiCamera, the focus of the camera needs to be adjusted manually to ensure that the ArUco codes on the bees are captured clearly and not blurred.

  - start the Raspberry pi with the camera in one flower half, with the glass piece in front and the marked dummy bumblebee in position in front of the feeder

## LEDs
Each Roboflower has 2 RGB LEDs wired in parallel, and one white LED. Make sure that the RGB LEDs light up in each colour (Red, Green and Blue)
when the flower is booting, before starting an experiment. The white LED should be turned on at all times.

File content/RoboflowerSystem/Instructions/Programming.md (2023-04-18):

# Programming the Roboflowers

This readme file explains the code of the roboflowers and details the whole step-by-step process of running experiments. For more details, please refer to the python modules for the full annotated code.

## Running experiments

### Starting an experiment
- connect the roboflower to the switch
- rename "expName" in the main.py of the HUB
- create a folder with the same name in the Home/Hub repository with the configurations YAML files inside:
  - contents.yaml
  - flowerGroups.yaml
  - rewardPatterns.yaml
  - UsedCodes.yaml
- modify these files accordingly depending on the experiment (see "Configuration YAML files" below)
- open main.py on the HUB via the terminal: python3 main.py
- start with a priming routine (probably 2 routines needed) (*p*) to check whether the pumps function properly and to allow the liquid to transit to the feeder
- start the experiment: *a*

### When an experiment starts:

When a roboflower boots, the raspberry pi runs by default the module "main.py" in home/roboflower, because of the line "python3 main.py" in flowerBoot.sh in the profile.d folder (rootfs/etc).

In main.py (Flower):
- import every main module in Flower: camera, electronics, MQTT from connect and routines
- instantiates a "cam" object from the Cam class in the camera module
- instantiates a "markers" object from the Markers class in the camera module
- instantiates a "feeder" object from the Feeder class in the electronics module:
	- the feeder object takes for arguments the 4 pins associated with motors from the Pump class in electronics, the pigpio daemon and the "UlForTurn" value 	for each pump
- instantiates a "led" object from the colorLED class in the electronics module:
	- the led object takes for arguments the RGB pins and the pigpio daemon
- instantiates a "mqtt" object from the MQTT class in the routines module
- makes a short routine to test that the red, green and blue pins work fine:
	- blink the 2 RGB LEDs in green for 2sec
	- blink the 2 RGB LEDs in blue for 2sec
	- blink the 2 RGB LEDs in red indefinitely until the flower receives a command from the HUB

- 3 cases depending on the command typed in the HUB:
1. if "mqtt.got_wakeup_message" = True (<=> typed "a" command in the console of the main.py of the HUB):
	- toggle "got_wakeup_message" to False
	- calls the "experiment" function from the routines module (see "Explanation of routines.py" what happens next)
2. if "mqtt.got_prime_message":
	- toggle"got_prime_message" to False
	- calls the "do_prime" method of feeder
3. if "mqtt.got_learn_message":
	- toggle "got_learn_message" to False
	- calls the colonylearn function of routines

### Training bees on the system

Before starting an experiment with the roboflowers, the colony needs to familiarise with the system. The learning mode should be "on" during the day and stopped every evening using the "q" command in the HUB to get the data of the day (log/debug files). See next section "Understanding the code/function "colonylearn" for all informations on how the learning mode works.

*note* in this mode: scent and quality are "None" and the retention time is set on 60second

- Step-by-step of the learning mode:
	- type "l" in the main.py of the HUB to start the function "colonylearn" from routines
	- the flowers all dispense 50uL of sucrose of a fixed quality of choice, and refill automatically every minute
	- at the end of the day, every bee marker is saved in a "seenmarkers" list displayed in the console of the HUB
	- log and debug files are created in the same way as in an experiment
	- every bee entering in a flower is recorded for 5seconds to check whether the bees learned successfully to use the system

### Configuration YAML files (HUB):
Each experiment depends on 4 configuration files which describe the characteristics of the flower meadow:

*note*: in these files, write the quality in milimol (example: 1000 for 1M), the quantity in ul*1000 (example 10000 for 10uL) and the retention in seconds.

- UsedCodes.yaml: stores the aruco markers used for the experiment
- flowerGroups.yaml: groups the flowers used in the experiment in 4 different flower groups: A, B, C and D
- contents.yaml: for each flower group, details the quality of the solution in pumps 1 and 2 and the colour of the flowers of this group
note: the fact that each flower has 2pumps give 2 opportunities of different rewards given by the same flower!
- rewardPatterns.yaml: 4 different bee groups: 1 to 4. In each of these bee groups you have the 4 flower groups A-D. For each group are precised the rewards that this group of bees will get when entering in the flowers of groups A-D:
	- the quality, quantity, scent and retention time <=> the "quality" then determines if pump 1 or 2 will give rewards to each bee!

RECAP of the configuration of an experiment:
- flowerGroups.yaml: determines which flowers belong to each flower group (4): A to D
	- example: fl1 and fl2 are in group A, fl3 and fl4 are in group B
- contents.yaml: determines the quality and scent of solution in pumps 1 and 2 + the colour of flowers for each group
	- example: group A: fl1 and fl2 are green:
			- pump 1 gives 1M sucrose
			- pump 2 gives 0.3M sucrose
		     group B: fl3 and fl4 are blue:
			- pump 1 gives 1.2M sucrose
			- pump 2 gives 1.6M sucrose
- rewardPatterns.yaml: - determines groups of bees (4): 1 to 4
			     - determines for each bee group and each flower group if the flowers give food from pump 1 or 2
	- example: - group 1: [bee markers 1 - 10]
				- flowers of group A (=green flowers) will give to this group:
					- quality 1 or 2 (determining if pump 1 or 2 will be at work for this bee!)
					- x quantity of solution
					- y scent (determining if pump 1 or 2 will be at work for this bee!)
					- the feeder will refill every z minutes (retention time)
				- flowers of group B (=blue flowers) will have:
					- quality a or b (determining if pump 1 or 2 will be at work for this bee!)
					- x' quantity of solution
					- y' scent (determining if pump 1 or 2 will be at work for this bee!)
					- the feeder will refill every z' minutes (retention time)
			- group 2: [markers 11 - 20]: idem!

This system allow each roboflower to be able to give 2 different types of (sucrose) solution. For each of these solution, the flower can give different quantities and have different retention times for each group of bees!

### Communication system - Mosquitto

Mosquitto is a messaging protocol (MQTT) taking care of the communication between the roboflowers and the main computer (HUB) in our system. See next section "Understanding the code/Mosquitto" for all informations about the communication system.

**Elements of the Mosquitto system:**
- **main computer** (<=> HUB) = publisher and broker. has the MQTT broker installed on it which acts as a central hub for all MQTT communication between the devices
- **switch** = network device: connects all the devices, including the main computer and Roboflowers, in a local area network (LAN)
- **roboflowers** = clients. They publish messages to topics or subscribe to topics to receive messages from other clients

### Getting data from experiments

See next section "Understanding the code/Explanation of connect.py" for all informations about the log and debug data files.

When running an experiment, data are logged in real-time to two data files:
- the debug files are the "human readable" version of the log files
- the log files are used to extract data from, in order to analyse them using python/excel

The debug files have a header of 3 variables: time, flower, message
	- the message element of debug files have one value: the event is explained in a clear sentence
The log files have a header of 8 variables: time, flower, id, pump, quality, scent, amount, event
	- the message element of log files are composed of 6 values: ID, pump, quality, scent, amount, event
		- these values are separated by commas and are meant to be extracted later to create a usable datasheet for experiment analysis

## Understanding the code

### Explanation of connect.py (HUB):
- contrary to the Flower module, the connect.py of the HUB also imports the "Thread" function from the threading library

A. the MQTT class
1. on_message function:
idem as in the connect.py of the Flower, except that the message to decode is not stored in last_message_received but is already in the format:
topic, timestamp, sender, mess

2. decode function:
receives two kind of topics; log/debug or commands:
- if the topic is log or debug:
	- calls the log method of the logger class and passes in the arguments: topic, timestamp, sender, and mess
- if the topic is commands:
	- if mess = turnedon: appends the ID of the sender (flower) to the ONflowers list
	- if mess = turnedoff: removes the flower ID to the ONflowers list
	- if mess = stillhere: appends the ID of the flower to the stillONflowers list and print "f4: still here" in the console of the main.py (because decode is called in the on_message function which is a callback of the MQTT class and is instantiated in the main.py)
	- if mess = awaits: 
		- assigns to a variable called "receiver" the "sender" elements of the message payload. example: f4
		- checks in which group f4 is in the flowerGroups dictionary: A, B, C or D
		- assigns to a variable called "yourgroup" the matching group letter
		- creates the variable "mess" later used in the connect.py of the flower! the structure of "mess" is taken from the YAML file "contents":
			- "quality_pump1, quality_pump2, scent_pump1, scent_pump2, colour_flower"
		- sends the "mess" to the sender (flower) through MQTT under the topic 'contents'
		- iterates through the lines of the rewardPatterns YAML file:
			- creates an empty "bees" variable
			- iterates through the "bees" in the current reward pattern
			- appends the ID of each bee separated by a hyphen to the "bees" string
			- generates a "mess" variable later used in the connect.py of the flower! the structure of "mess" is from the rewardPatterns YAML file:
				- "rewardPattern, bees, quality, quantity, scent, retention"
			- sends the "mess" to the sender (flower) through MQTT under the topic 'rewards'
	recap: the message "awaits" assigns the different elements of the system to the parameters in the configuration YAML files and waits for further instructions:

3. function "send":
this function points to receiver=all, meaning that every message (=load) published by the HUB is sent via MQTT to every flower!
- creates a "load" variable in the format: date/time - from HUB to sender: *message*
- publishes the load through the publish() method to the according topic
- print the load in the main.py of the HUB. example:  "date - from HUB to all: check"

4. function "keepchecking"
infinite loop that checks flowers present in the "ONflowers" list and sends a command message "check" to flowers every minute for them to respond with a
" - still here" if they are connected, and to respond with a " is not responding anymore" if not!
reminder: in the flower's "do" function, the command "check" sends a "stillhere" message under the "commands" topic. This "stillhere" message triggers the receiver (flower) to respond with a ": still here" if present in the "stillONflowers" list

5. function "do_keepchecking":
is a deamon (=thread) of the keepchecking function, so that it runs in a thread <=> in the background while the rest of the program can continue executing other functions.

6. function "stop":
simple function linked to the keepchecking and keepchecking deamon: stops the keepchecking loop and waits for the do_keepchecking thread to finish

B. The Logger class:
generates the log and debug files. The log() method within the class writes to these files:
*note* in the log file, quality is already in M and quantity in ul

- generates two files for log and debug in the data directory, and their name follow the following format:
	- 2023-03-19_13:23:00.log
	- 2023-03-19_13:23:00.debug
- opens the log and debug files in write mode and creates a header row with the following 8 variables:
	- log: 'time, flower, id, pump, quality, scent, amount, event'
	- debug: 'time, flower, message'

function "log":
writes to the log and debug files.
- takes as arguments: topic (either log or debug), t (timestamp), s (sender) and m (message)
- if topic = log:
	- extracts the 6 values from "m": "ID, pump, quality, scent, amount, event" and split them by commas
	*note* always check that any message sent to the log file have 5 commas <=> 6values!
	- opens the log file in append mode and writes a line of comma-separated values consisting of a total of 8 values (consistent with the header length):
            - timestamp, sender, m
	- print it to the console of main.py as well in the format:
		- time - f4, bee 10: pump1 gave xM of scent and yuL: event
- if topic = debug:
	- the message "m" in this case is just one element: the event. Debug does not report ID, pump, quality, etc.
	*note* always check that any message sent to the debug file no comma <=> 1value!
	- opens the debug file in append mode and writes a line of comma-separated values consisting of a total of 3 values:
            - timestamp, sender, m
	- print it to the console of main.py as well in the format:
		- time - f4: event

### Explanation of connect.py (Flower):
- the Client class from the library mqtt-paho is imported
- the client (= flower) subscribes to the topics "commands", "contents" and "rewards" <=> the flower will receive messages published to these topics by other clients connected to the broker
- lines 20-22 of the connect.py module:
        self.client.on_connect = self.on_connect
        self.client.on_disconnect = self.on_disconnect
        self.client.on_message = self.on_message 
These 3 callback functions are automatically executed when the MQTT class is instantiated somewhere: the class is called in the main.py of the flower, so the functions on_connect, on_disconnect and on_messages are executed in the main! and also any message will be printed in the console of this script :)
note: the function "decode" is also automatically executed in the main.py because is called in the on_message function. Same for the functions "do" which is called in the decode function, and "send".

1. function "on_message" from the MQTT class:
this function is responsible for transforming messages sent via MQTT (in bytes) into strings.
this new string message is parsed into 4 parts separated by dots: timestamp.sender.receiver.mess
these 4 elements are stored in a dictionary called last_message_received
The structure of the element "mess" from last_message_received depends on the topic of the MQTT message:
- if the topic = commands, the message is either: wakeup, kill, check, prime or learn
- if the topic = contents, the message looks like: quality_pump1, quality_pump2, scent_pump1, scent_pump2, colour_flower
- if the topic = rewards, the message looks like: reward_pattern, list-of-bees, quality, amount, scent, retention

2. function "decode":
the last_message_received is decoded by the decode function
- if the topic = commands: get the "message" element of last_message_received and apply it to the "do" function
- if the topic = contents: 
	- splits the "message" element of last_message_received and print it in the main.py of the flower as follow:
		"quality pump1: xM, quality pump2: yM"
		"scent pump1: *scent*, scent pump2: *scent*"
		"colour of flower: *colour*"
	- separates the different values of the message element in variables:
		- self.qualities = elements 1 and 2
		- self.scents = elements 3 and 4
		- self.color = element 5
	- sends 2 debug messages via the send() function:
		"pump 1 contains xM, *scent* solution"
		"pump 2 contains yM, *scent* solution"
	- "gotcontent" attribute becomes True
- if the topic = rewards:
structure of the self.rewardpatterns dictionary from the MQTT class:
{
    reward_pattern_1: {
        'bees': [bee_1, bee_2, ...],
        'amount': amount_value,
        'retention': retention_value,
        'quality': quality_value,
        'scent': scent_value,
        'pump': pump_number
    },
    reward_pattern_2: {
        'bees': [bee_1, bee_2, ...],
        'amount': amount_value,
        'retention': retention_value,
        'quality': quality_value,
        'scent': scent_value,
        'pump': pump_number
    },
    ...
}
	- takes the first element of "message" from last_message_received and make it a variable called rewardpattern
	- initializes an empty dictionary for the "rewardpattern" key in the self.rewardpatterns dictionary
	- assigns to the "bees" key the second element of "message" from last_message_received which is a list of bees and separate them with commas
	- creates variables associated with the next elements of "message" from last_message_received: quality, amount, scent and retention
	- based on whether the quality and scent of the incoming message corresponds to pump 1 or 2, sends a message to debug using the send function:
		- "reward pattern x is associated with pump 1" (or pump 2)
	- if the quality/scent don't match pumps 1 or 2, send a debug message:
		- "cannot find the correct pump"
	- sets the 'gotreward" attribute to True
	- prints in the console of the main.py of the flower: 
		- timestamp, flower, reward pattern 1 associated with pump 0
		- timestamp, flower, reward pattern 1 associated with pump 1
	
3. function "do":
- takes "command" as a parameter
- if the command = "wakeup":
	- sends "commands" and "turnedon" via the send() function (see below)
- if the command = "kill":
	- sends "commands" and "turnedoff" via the send() function
- if the command = check:
	- sends "commands" and "check" via the send() function
- if the command = prime:
	- sends "commands" and "received" via the send() function
- if the command = learn:
	- sends "commands" and "received" via the send() function
	
4. function "send": this function points to the HUB, meaning that every publication by the roboflowers are sent to the HUB
- takes 3 parameters: topic, message and receiver; receiver is set on "HUB"
- creates a string "load" in the format: current_time: flower_name HUB message
- publishes "load" to the specified topic using the publish() built-in function from paho library
- prints "load" in the console of the main.py of the flower. Example:
	Apr 5 14:50:21 2023 - from f4 to HUB: message (depends on the topic)

### Explanation of routines.py (Flower):

This module has 2 big functions: experiment and colonylearn. These 2 functions put together every module to make the whole system work, ie. the electronics part, the communication part, the camera and the configuration files.

*note:* the routines module, although using the classes and functions of every other module, interacts with them *only* in the main.py of the flower! When the experiment function is defined in routines, its arguments mqtt, led, cam, markers and feeders are instantiated in the main.py for it to use them.

A. function "experiment":
- takes 5 arguments: mqtt, led, cam, markers and feeder (defined as instances of MQTT, colorLED, Camera, Markers and Feeders of other modules in main.py)
- sends the message "I woke up" under the "debug" topic using the send method of the MQTT class
- blinks the RGB LEDs in green for 2sec using the blink method of colorLED class
- sends the message "awaits" under the topic "commands" using the send method <=> assigns the different elements of the system to the parameters in the configuration YAML files
- waits until mqtt.gotcontents and mqtt.gotrewards are updated to True to proceed
-     led.on(mqtt.colors[mqtt.color])  # turns on the RGB LEDs using the "on" method of the colorLED class and the color method of the MQTT class, fetching the right color from the config file
- prints the colour in the main.py of the flower
- starts the camera with the start() module of the Camera object and wait 2sec (for the camera to properly start)
- send messages under the topics debug and log:
	- to debug: "camera started" (because mess = 1 value in debug) and " save this time as: " (idem)
	- to log: " NA,NA,NA,NA,NA,started" (because mess = 6values in log)
	- creates an empty dictionary "thisbee" with 3keys: id, pump, amount
	- do a cleaning routine (<=> pump 3 = +12uL, pump 4= -21uL, pump 3 = +9uL) using the do_clean method of the function feeder

starts the experiment in a huge infinite loop: define the behaviour of the pumps and the communication for every bee scenario arriving/leaving the flowers:
- assigns to the variable "now" the current time
- captures frames from the camera using the grab() method of the cam object (instantiated in the main.py)
- detects markers in the frames using the detect() method of the markers object (idem)

- if markers.bee_arrived = True (method bee_arrived from the track method of the Markers class in Camera):
	- sends a message under the log topic in the format:
		- markers_last_seen,NA,NA,NA,NA,bee arrived'
	- toggle markers.bee_arrived to False

- if markers.bee_gone = True:
	- sends a message under the log topic in the format:
            - markers_last_seen,NA,NA,NA,NA,bee gone'
	- toggle markers.bee_gone to False

1. main big case: if the camera is currently detecting a marker (markers.being_seen) and the detected markers.ID is not None and the marker has not already been recognized (not markers.beenRecognized):
	- the recognize() method of the markers object takes in the rewardpatterns dictionary the reward pattern matching the bee ID
	- assigns it to "thisbeepattern" variable
	- if not markers.beenRecognized: say that an unexpected marker was seen and add this marker to "ID" + say it in debug
		- if the detected marker ID (str(markers.IDs[0][0])) is not in the second element of any tuple in the markers.beenNotified list (this second 			element contains the ID of a previously detected but not recognized marker):
			- send under the "debug" topic: " seen a  marker not expected: bee_ID"
		- in the list (markers.beenNotified), bees markers notified more than 30sec ago are removed from the list so that the camera can detect new markers
	a. if markers.beenRecognized <=> if a bee is being seen by the camera:
		- assigns to the "ID" variable markers.IDs[0][0] (= bee marker)
		- sends a message under the "debug" topic: " seen a marker: ID"
		- assigns to the "lastentered" variable this ID
		- if not feeder.full:
			- if ID in feeder.visitors: if the ID of the bee is already in the "visitors" dictionary of the feeder:
				- if the time elapsed since the last time the feeder was emptied for this bee ID is greater than the retention time:
					- sets for "thisbee" the ID, pump, amount, quality, and scent of the reward pattern for this bee
					- the feeder is filled using thisbee['pump'] and thisbee['amount'] values
					- sends under the "debug" topic: "giving to bee bee_id solution from pump X of quality YM and scent for Xul
					- sends under the "log" topic: "10,1,1.0,unscented,50.0,filling"
					- the "when_filled" key of the feeder.visitors[ID] dictionary is updated with the current time
				- if the retention time has not elapsed for thisbee:
					- sends under the "debug" topic: " I have seen bee_ID but the retention time has not elapsed'
					- sends under the "log" topic: bee_ID,NA,NA,NA,NA,retention'
			- if ID is not in feeder.visitors:
				- replace "thisbee[id] with the bee marker
				- replace thisbee[pump] and amount, quality and scents with according values in rewardspatterns
				- fill the feeder based on thisbee[pump] and amount
				- send under the "debug" topic: "giving bee_id solution from pump 1 of quality xM unscented for yul"
				- send under the "log" topic: "10,1,1.0,unscented,50.0,filling"
				- fill in the element "when_filled" of the key feeder.visitors[ID] with the current time
		- if feeder.full:
			- send under the "debug" topic: " the feeder is full already"
			- send under the "log" topic:  "bee_id,NA,NA,NA,NA,feeder full"
	b. if not markers.being_seen:
		- if feeder.full:
			- if it's been more than a minute that the feeder was last filled (for a previous bee):
				- send under the "debug" topic: " no bee, emptying the feeder"
				- send under the "log" topic: "NA,NA,NA,NA,NA,empty"
				- feeder.do_flush(80000) <=> pump 4 flushes out 80uL
				- sets the current time for the "when_emptied" element of the feeder.visitors[thisbee['id']] key
2. if mqtt.got_prime_message <=> receive a "p" command:
	- feeder.do_prime(): do the priming routine
	- toggle the got_prime_message to False
3. if mqtt.got_kill_message <=> receive a "k" command:
	- send under the "debug" topic: "I got turned off :( Goodnight!"
	- turns the RBG LEDs off
	- breaks from the experiment function

B. function "colonylearn":
- takes 5 arguments: mqtt, led, cam, markers and feeder just like the "experiment" function
- creates an empty list called "seenmarkers" (line not in experiment)
- sends the message "I woke up in learning mode" under the "debug" topic
- turns off the RGB LEDs
- sends the message "awaits" under the topic "commands" using the send method <=> assigns the different elements of the system to the parameters in the configuration YAML files
- starts the camera with the start() module of the Camera object and wait 2sec (for the camera to properly start)
- send under the "debug" topic: " camera started" followed by " save this time as 0"
- send under the "log" topic: "NA,NA,NA,NA,NA,LearnStarted'
- creates an empty dictionary "thisbee" with 3keys: id, pump, amount

starts the colonylearn in a big infinite loop: this function runs in the first days before an experiment to allow the bees of the colony to learn how to use the flowers:
*note* in this scenario: scent and quality are "None" and the retention time is set on 60seconds
- captures frames from the camera using the grab() method of the cam object (instantiated in the main.py)
- detects markers in the frames using the detect() method of the markers object (idem)
- *addition of colonylearn which is not in experiment*: displays the captured frame in a window called 'f' using the built-in imshow() function from opencv
- waits for 1 millisecond (necessary to ensure that the window is updated and remains responsive)

1. main big case: if the camera is currently detecting a marker (markers.being_seen) and markers.IDs is not None and has not already been recognized (not markers.beenRecognized):
	- toggle markers.beenRecognized to True
	- assigns to the "ID" variable markers.IDs[0][0] (= bee marker)
	- appends the bee marker to the "seenmarkers" list created at the beginning of the function [addition colonyLearn; not in experiment]
	- sends under the "debug" topic: "seen a marker: bee_id"
	- if not feeder.full <=> if empty feeder:
		- if more than 60sec have passed since the last time the feeder was emptied:
			- thisbee['id'] is set with the ID of the bee
			- sets the thisbee['pump'] to 0 <=> pump 1
			- sets thisbee['amount'] to 50000 <=> 50uL of sucrose, feeder completely full
			- sets "quality" and "scent" of thisbee to "null"
			- fills the feeder according to thisbee['pump'] and thisbee['amount'] values
			- sends under the "debug" topic: "giving bee_id solution from pump 1 of quality None and scent None for xul
			- sends under the "log" topic: bee_id,1,None,None,50,filling
		- if the feeder was last emptied less than a minute ago:
			- sends under the "debug" topic: " I have seen bee_id but the retention time has not elapsed"
			- sends under the "log" topic: "bee_id,NA,NA,NA,NA,retention"
	- if feeder.full:
		- sends under the "debug" topic: " the feeder is already full"
2. if no marker is being seen:
	- if feeder.full:
		- sends under the "debug" topic: " no bee: emptying the feeder"
		- feeder.do_flush(100000) <=> flushes out 100uL
3. if mqtt.got_prime_message:
	- feeder.do_prime()
	- toggle got_prime_message to False
4. if mqtt.got_kill_message <=> receive a "k" command:
	- send under the "debug" topic: "I got turned off :( Goodnight!"
	- [addition colonyLearn]: " in the end I have seen today: _bee_markers"
	- breaks from the experiment function

### Communication system - Mosquitto

Mosquitto is an open-source message broker that implements the MQTT (Message Queue Telemetry Transport) protocol. 
It is a lightweight publish/subscribe messaging protocol. MQTT is an ideal protocol for constrained devices such as sensors and microcontrollers.

### Functioning of the Mosquitto server

In Mosquitto, clients can connect to the broker and publish messages to topics or subscribe to topics to receive messages from other clients. The broker acts as a central hub for all messages, receiving and routing them to the appropriate clients based on their subscription interests.
Clients connect to the broker and communicate through packets, such as CONNECT, PUBLISH, SUBSCRIBE.

**Elements of the Mosquitto system:**
- **main computer** (<=> HUB) = publisher and broker. has an MQTT message broker installed on which acts as a central hub for all MQTT communication between the devices. 
- **switch** = network device: connects all the devices, including the main computer and Roboflowers, in a local area network (LAN).
- **roboflowers** = clients. They publish messages to topics or subscribe to topics to receive messages from other clients. 

The HUB is subscribed to these MQTT topics:
```python
	self.client.subscribe('commands')
	self.client.subscribe('log')
	self.client.subscribe('debug')
	self.client.subscribe('contents')
	self.client.subscribe('rewards')
```

The Roboflowers are subscribed to these MQTT topics:
```python
	self.client.subscribe('commands')
	self.client.subscribe('contents')
	self.client.subscribe('rewards')
```

### Programming the Mosquitto server

**1. Mosquitto on the HUB**

Setting up an MQTT communication between the main computer and the Roboflowers, i.e. installing the Mosquitto broker on the main computer:
- in the terminal: *sudo apt-get update*
- install the Mosquitto broker package: *sudo apt install mosquitto* - enable the Mosquitto broker to start automatically at boot time
- start the Mosquitto broker: *sudo systemctl start mosquitto* **or**:

- update Mosquitto to the latest version: *sudo apt-get upgrade mosquitto*

- restart the Mosquitto service to apply the changes: *sudo systemctl restart mosquitto*
- by default, Mosquitto broker listens on port 1883 for MQTT traffic. Verify that the Mosquitto broker is running: *sudo systemctl status mosquitto*
  
(If the broker is running, you should see a message that says "Active: active (running)" in the terminal window)

**2. Mosquitto on the Roboflowers**

Installing the Mosquitto client on the Raspberry pis:
- the paho-mqtt Python library takes care of integrating MQTT communication into the Python code running on the Raspberry Pis
- the mqtt.Client class creates an MQTT client that can connect to the Mosquitto broker

**3. Debugging MQTT**

Error: "MQTT already in use" : could mean that another MQTT broker or client is already running on the HUB and using the default MQTT port (1883). solution:
- stop the Mosquitto service: *sudo systemctl stop mosquitto*
- check if any other MQTT broker or client is running on the HUB: *sudo netstat -tlnp | grep 1883*
- kill the process, by replacing the PID with the right one (listed in the second column of output above): *sudo kill -s SIGTERM PID*
- start the Mosquitto service again: *sudo systemctl start mosquitto*

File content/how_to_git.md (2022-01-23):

# Git and GitHub Guidelines

Coming soon!

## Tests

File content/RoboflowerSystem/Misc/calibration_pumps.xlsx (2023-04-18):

date | pump number | pump type | testing method | mean distance for 1 turn (mm) | uL for 1 pump turn | comments
2023.03.15 | P51 | 1, 2 or 3 | calibration station | 31.5 | 6.1 | leaking! Discarded
2023.03.17 | P51 | 1, 2 or 3 | calibration station | 33.3 | 6.5
2023.03.20 | P51 | 1, 2 or 3 | calibration station | 32.3 | 6.34
2023.03.15 | P19 | 1, 2 or 3 | calibration station |  | 5.89
2023.03.17 | P19 | 1, 2 or 3 | calibration station |  | 5.69
2023.03.20 | P19 | 1, 2 or 3 | calibration station | 27.2 | 5.34
2023.03.17 | P14 | 4 | calibration station | 28.97 | 5.69
2023.03.20 | P14 | 4 | calibration station | 28 | 5.5
2023.03.17 | P88 | 1, 2 or 3 | calibration station | 28 | 5.5
2023.03.20 | P88 | 1, 2 or 3 | calibration station | 28.5 | 5.6
2023.04.16 | P57 | 1, 2 or 3 | calibration station | 26.7 | 5.3
2023.04.16 | P57 | 1, 2 or 3 | calibration station | 26.7 | 5.3
2023.04.16 | P57 | 1, 2 or 3 | calibration station | 26.7 | 5.3

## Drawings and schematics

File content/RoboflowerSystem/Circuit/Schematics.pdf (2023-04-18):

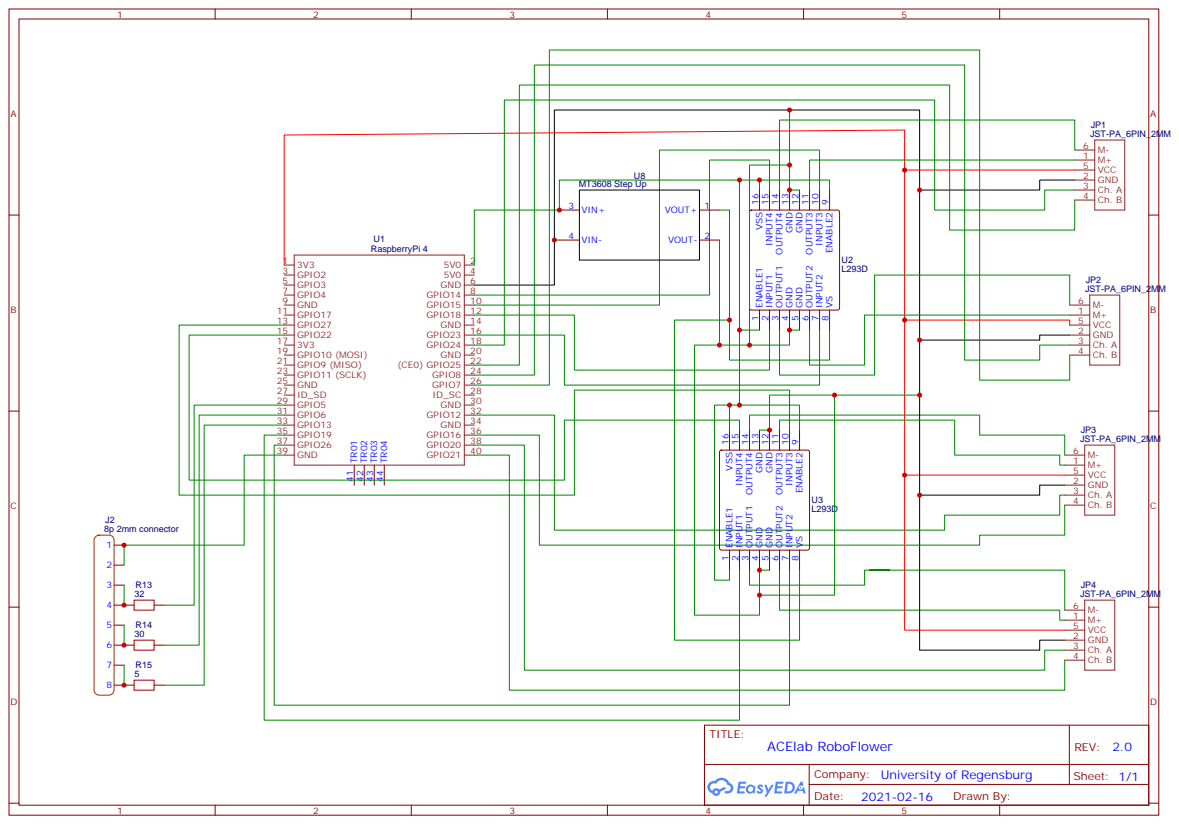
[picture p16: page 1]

VS 8 ENABLE2 9 INPUT3 10 OUTPUT3 11 GND 12 GND 13 OUTPUT4 14 INPUT4 15 VSS 16

Company: University of Regensburg
